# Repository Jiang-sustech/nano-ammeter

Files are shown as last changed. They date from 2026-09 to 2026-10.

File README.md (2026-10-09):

# 纳安表 (Nano-Ammeter)

基于电荷平衡原理的微弱电流测量仪，面向光电效应、脉冲电流等 pA 级测量场景。
硬件、固件、上位机与 PC 脚本全部开源。

## 1. 性能

| 项目 | 指标 | 条件 |
|---|---|---|
| 直流量程 | ±45 nA | 受参考电流 ±50 nA 限制 |
| 显示分辨率 | 0.01 pA | 固件量化 |
| 单次重复性 | 0.027 pA | 50 s 积分窗，1 pA–500 pA 段 31 点合并 |
| 线性度（校准后）| 0.0046 %FS | 162 点，满量程 ±45 nA |
| 脉冲峰值 | 4.2 µA | 超直流量程 93 倍，偏差 −0.58% |

装置输出量即积分窗口内的平均电流

$$I_{\text{out}}=\frac{1}{\tau}\int_{t-\tau}^{t} i(t)\,\mathrm{d}t$$

故对脉冲输入无需峰值检波、频谱搬移或同步采样，峰值远超直流量程时仍可正确读出等效平均值。

## 2. 仓库结构

| 目录 | 内容 |
|---|---|
| [`hardware/`](hardware/) | 嘉立创 EDA 源工程（含 BOM、网表）、原理图、4 层 Gerber |
| [`firmware-v1/`](firmware-v1/) | 固件，现役版本 |
| [`firmware-v0/`](firmware-v0/) | 固件，2026-09-13 冻结基线，只读 |
| [`pc-console/`](pc-console/) | 上位机：Web Serial 控制台 |
| [`scripts/smu/`](scripts/smu/) | 2636B 源表控制与采集 |
| [`scripts/plotting/`](scripts/plotting/) | 绘图 |
| [`scripts/analysis/`](scripts/analysis/) | 标定、拟合、线性度分析 |
| [`scripts/lib/`](scripts/lib/) | 公共模块，被上述脚本 import |
| [`scripts/misc/`](scripts/misc/) | 烧录与杂项 |
| [`docs/`](docs/) | 排障记录、实验方案、论文节 |
| [`data/`](data/) | 实测数据 |
| [`image_paper/`](image_paper/) | 论文插图 |
| [`prototypes/`](prototypes/) | 历史固件归档，只读 |

脚本索引与依赖关系见 [`scripts/README.md`](scripts/README.md)。

## 3. 硬件 `hardware/`

| 文件 | 说明 |
|---|---|
| `jlc-project.zip` | 嘉立创 EDA 专业版工程（原理图 + PCB + BOM + 网表）|
| `Schematic.png` | 原理图 |
| `gerber/` | Gerber 制板文件（4 层板 + 3 个钻孔文件）|
| `enclosure.stp` | 铝合金外壳 3D 模型（STEP）|

`jlc-project.zip` 解压得 `.epro2`，经嘉立创 EDA（专业版）`文件 → 打开工程` 导入；
元件属性含立创商城料号，可直接下单。

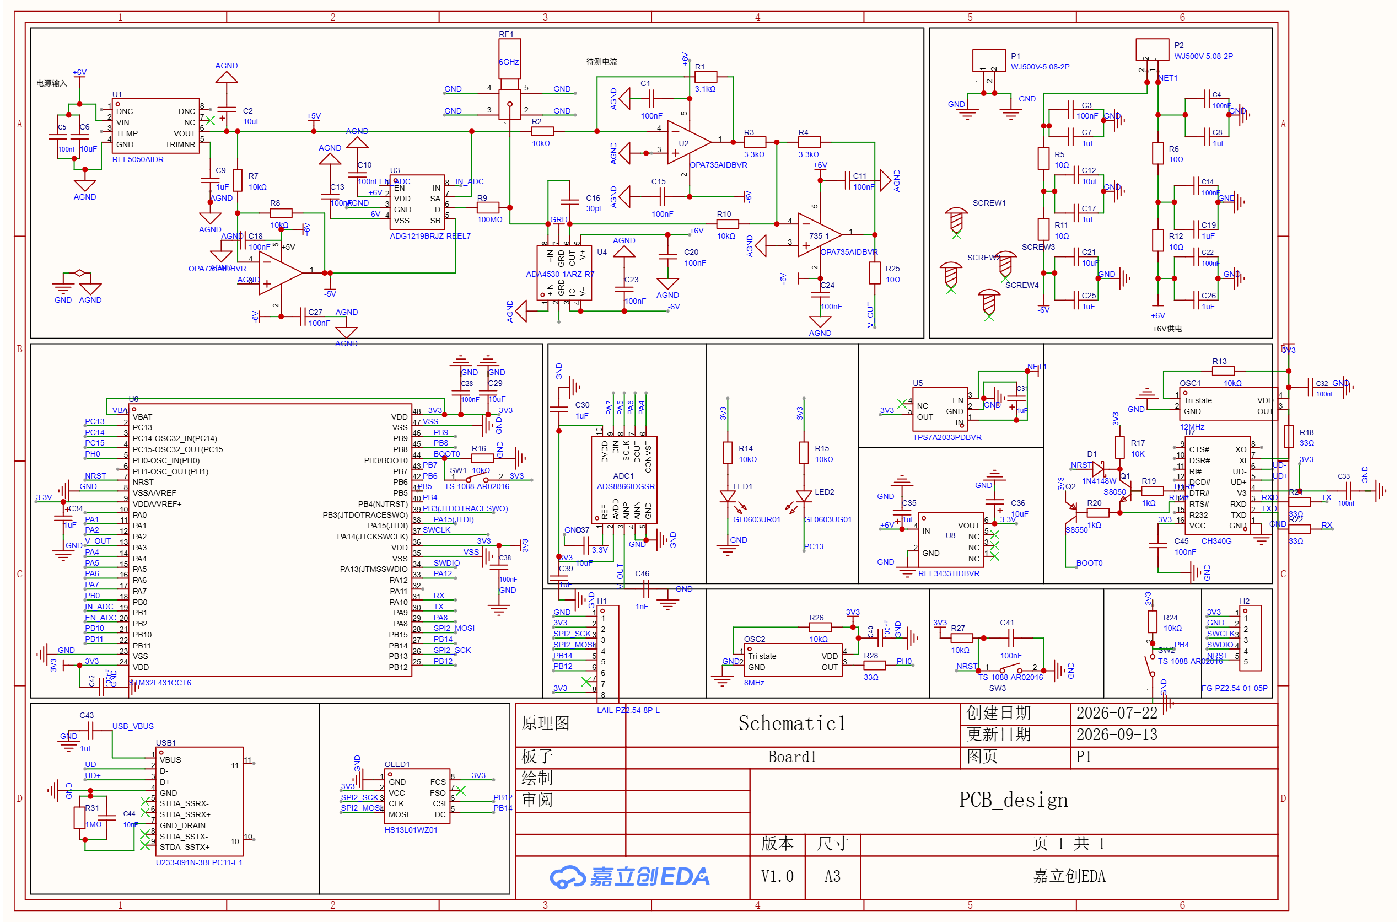
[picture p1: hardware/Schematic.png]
原理图


**板级配置**

| 项 | 器件 |
|---|---|
| MCU | STM32L431CCT6 |
| 模拟前端 | ADA4530 静电计运放（积分电容 100 pF）+ ADG1219 参考开关 + OPA735 电平移位 |
| 采集 | 内置 12-bit ADC（控制路）+ ADS8866 16-bit（观测路，SPI）|
| 显示 / 通信 | SH1106 1.3" OLED（SPI）/ 板载 CH340G（USB-C）|
| 参考电流 | ±50 nA（±5 V 经 100 MΩ，标称值）|

> 元件值均为标称值，绝对增益尚未标定；实测参考电流与积分电容值见
> [`firmware-v1/Core/Inc/current.h`](firmware-v1/Core/Inc/current.h)。

## 4. 固件 `firmware-v1/`

STM32L431 固件，CMake 工程（亦可由 CubeIDE 打开）。**固件改动仅限本目录**；
`firmware-v0/` 为冻结基线（只读），缺 50 s 长窗、拉回相、`X=` 字段与 `T<ms>` 指令，
不支持亚纳安测量。

`Core/Src/` 模块划分：

| 模块 | 职责 |
|---|---|
| `main.c` | 主循环、串口指令分发 |
| `measurement_state.c` | 测量状态机（空闲 / 拉回相 / 模式一 / 模式二）|
| `current.c` | ±50 nA 参考、式(6) 计算、分段校准 |
| `adc.c` `ads8866.c` | 双路同拍采集 |
| `cal_coef.c` `cal_mode.c` | 校准系数存储（Flash + CRC）、标定模式 |
| `sh1106.c` | OLED 显示 |
| `uart.c` | 串口协议、波形回传 |
| `tim.c` `spi.c` `gpio.c` `button.c` | 外设 |

```bash
cd firmware-v1
cmake --preset Debug && cmake --build build/Debug
# 产物：build/Debug/firmware-v1.elf
```

烧录：ST-Link + OpenOCD（`scripts/misc/run_app.sh` 可绕过"复位进 ROM bootloader"），
或串口 bootloader（`scripts/misc/uart_flash.py`）。

串口协议见 §9；固件内部细节见 [`firmware-v1/README.md`](firmware-v1/README.md)。

## 5. 2636B 源表控制与采集 `scripts/smu/`

Keithley 2636B（LAN / pyvisa），用于标定与表征；另含本装置的串口采集。

| 脚本 | 用途 |
|---|---|
| `cal_sweep.py` | 底层驱动（串口 + 源表 + 测量原语）|
| `sweep_dense.py` | 密集电流网格扫描（整窗回传）|
| `sweep_broad.py` `sweep_dc.py` `sweep_iv.py` | 宽范围 / 直流 / 光电探测器 I–V 扫描 |
| `sweep_pulse.py` | 脉冲采集（TSP 脉冲源）|
| `nanoammeter_capture.py` | 单次采集 → npz / png / log（v1 需 `--no-noise`）|
| `test_smu.py` | 源表连通与功能自检 |
| `warm_test.py` | 预热必要性对照 |
| `pulse_real.py` `pulse_probe.py` `pulse_introspect.py` | 脉冲重建 / 能力探针 / 内省 |
| `measure_transient.py` `switching_times.py` `range_test.py` | 瞬态 / 开关时序 / 量程效应 |
| `test_capture.py` | `nanoammeter_capture` 离线回归（26 项）|

```bash
pip install pyvisa pyserial numpy matplotlib
python scripts/smu/test_smu.py
python scripts/smu/nanoammeter_capture.py COM8 --no-noise
```

> `cal_sweep.py` 的 `MEASURE_TIMEOUT_S` 必须覆盖固件最长窗口（50 s → 已设 60）。

## 6. 绘图 `scripts/plotting/`

论文插图生成，统一风格见 `scripts/lib/paper_style.py`。

| 脚本 | 输出 |
|---|---|
| `paper_figs.py` | 低电流段图 |
| `paper_lin10_fig.py` | ±10 nA 组 |
| `paper_pulse_fig.py` | 脉冲四格图 |
| `photoelectric_fig.py` `photo_data_fig.py` `dark_current_fig.py` | 光电效应 / 光电数据 / 暗电流 |
| `residual_pct_plot.py` | ±5–45 nA 残差百分比图 |
| `console_figure.py` | 控制台截图（注入真实数据后 Chrome headless 渲染）|

## 7. 分析 `scripts/analysis/`

标定常数拟合、线性度、误差预算与脉冲分析。

| 脚本 | 用途 |
|---|---|
| `fit_constants.m` `make_fit_csv.py` | 三常数（M、I₊、I₋）最小二乘拟合 |
| `fit_linearity.py` `fit_tau.py` | 早期拟合链 |
| `cal_table.py` `detect_limit.py` | 标定表 / 检测下限 |
| `lowI_compare.py` | 误差链：装置 / 设定 / 源表回读 |
| `outlier_test.py` `.m` | 离群值检验（Python / MATLAB 互校）|
| `seg0_budget.py` `seg0_joint_fit.py` `fsw_hypothesis.py` | 低电流段偏置分析与假设检验 |
| `reproducibility.py` `endpoint_codes.py` `range_effect.py` `window_sawtooth.py` `raw_recalc.py` | 复现性 / 端点码 / 量程效应 / 锯齿形态 / 原始码反推 |
| `analyze_pulse.py` `sim_pulse_recover.py` | 脉冲分析 / 恢复仿真 |
| `matlab_utf8.sh` | MATLAB UTF-8 包装 |

推导见 [`docs/校准方案推导.md`](docs/校准方案推导.md)，操作步骤见
[`docs/拟合操作指南.md`](docs/拟合操作指南.md)。

## 8. 上位机 `pc-console/`

单文件 Web Serial 控制台，无外部依赖，Chrome / Edge 直接打开 `console.html`。

| 文件 | 说明 |
|---|---|
| `console.html` | 控制台；「一键采集」执行 `E→S→B→X→E`，「实验表征」面板负责逐点采集与系数收发（仅 v1）|
| `console_selftest.js` | 整体自测（36 项）|
| `console_src/archive.js` | 数据存档与命名模块，内联进 HTML |
| `console_src/archive_test.js` | 模块自测（18 项）|

```bash
node pc-console/console_src/archive_test.js
node pc-console/console_selftest.js
```

## 9. 测量与协议

**积分窗口**

| 电流 | 窗口 |
|---|---|
| $\lvert I \rvert \ge 1$ nA | 1 s |
| $\lvert I \rvert < 1$ nA | 50 s |

实测（1 pA–500 pA 段，31 点合并）：10 s 窗单次重复性 0.1153 pA，50 s 窗 0.0267 pA。
亚纳安段统一取 50 s，以保证光电效应实验 I–V 曲线过零点的判读精度。

**串口协议（115200 8N1）**

| 指令 | 功能 |
|---|---|
| `S` | 单次测量（测完回空闲）|
| `D` | 查询最近结果 |
| `B` / `X` | 回传窗口波形（内置 ADC / ADS8866），`"<tag> <count>\r\n"` + u16 小端 + 校验和 |
| `E` | 观测通路自检 |
| `Q` `Q<q_aC>,<i+_pA>,<i-_pA>` | 物理常数查询 / 写入（Flash，掉电不丢）|
| `K<段>,<a_ppm>,<b_fA>` `C` `Z` | 分段校准系数写入 / 查询 / 清除 |
| `T<ms>` | 强制积分窗口（`T0` 回自动）|

指令大小写不敏感，测量期间忽略。

## 10. 标定

式(6) 化简后仅需三个外部常数：

```
I = q·(c2 − c1)/T窗 − (m·I₊ + n·I₋)/N
  q = C·VREF/(65536·GAIN)   库仑/码   标称 1.5259e-14
  I₊, I₋                    参考电流  标称 ±50 nA
```

简化：① 电平移位 1.55 V 在 `Vo1 − Vo2` 中相消，无需标定；② `q` 的四个因子只测乘积。

| 量 | 方法 |
|---|---|
| `I₊` / `I₋` | 闭环最小二乘（`analysis/fit_constants.m`）|
| `q` | 灌已知电流开环测量，不依赖锯齿相位假设 |

> `q` 不可用"参考断开 + 灌电流"法：`EN=0` 为 Hi-Z 而非 0 A，浮空节点寄生电容会注入
> 衰减暂态电荷。见 [`docs/调试与排障.md`](docs/调试与排障.md)。

`firmware-v0` 常数存编译期宏；`firmware-v1` 存 Flash 末页（带 CRC），串口 `Q`/`K` 读写，
重新标定无需重编译。

## 11. 排障

调试手段、工程结论与待复核项见 [`docs/调试与排障.md`](docs/调试与排障.md)。

> 该记录对应一版存在设计缺陷的硬件，其中的硬件接线与结论不具通用性；作者将在开源方案
> 中发布修正后的硬件版本，届时以新版文档为准。

## 许可

尚未选定。
（硬件建议 CERN-OHL-P 或 CC BY-SA；固件与脚本建议 MIT 或 Apache-2.0。）

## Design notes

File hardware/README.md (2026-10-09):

# 硬件文件

纳安表的原理图与制板文件。

## 内容

| 文件 | 说明 |
|---|---|
| [`jlc-project.zip`](jlc-project.zip) | **嘉立创EDA专业版工程源文件**（原理图 + PCB + BOM + 网表）|
| [`Schematic.png`](Schematic.png) | 原理图（整页）|
| [`gerber/`](gerber/) | Gerber 制板文件（4 层板 + 3 个钻孔文件）|
| [`enclosure.stp`](enclosure.stp) | **铝合金外壳 3D 模型**（嘉立创 FA 壳体，STEP 格式）|

## 外壳（嘉立创 FA 铝合金壳体）

`enclosure.stp` 是整机的铝合金外壳模型（STEP AP214），导入 SolidWorks / Fusion 360 /
FreeCAD 等即可查看或二次修改。模型来自嘉立创 FA 的壳体定制服务。

> STEP 文件头里的作者字段（`Gilles Foucault` / `UJF`）是嘉立创导出模板的**默认占位**，
> 非设计者信息。

## 源工程（嘉立创EDA专业版）

`jlc-project.zip` 解压后是 `.epro2` 工程包，用**嘉立创EDA（专业版）**
`文件 → 打开工程` 直接导入。工程内已包含原理图、PCB 版图、BOM 与网表，
元件属性带立创商城（LCSC）编号，可直接下单。

> 源工程不含姓名、邮箱、本地路径等个人信息（仅含 LCSC 厂商/料号等公开数据）。

## 板子概况

- **4 层板**（`G1` / `G2` 为内层）
- MCU：STM32L431CCT6
- 模拟前端：ADA4530 静电计运放（积分电容 100 pF）+ ADG1219 参考开关 + OPA735 电平移位
- 采集：内置 12-bit ADC（控制路）+ ADS8866 16-bit（观测路，SPI）
- 显示：SH1106 1.3" OLED（SPI）
- 串口：板载 CH340G（USB-C）
- 参考电流：±50 nA（由 ±5 V 经 100 MΩ 得到，**标称值**）

## Gerber 层对应

| 文件 | 层 |
|---|---|
| `Gerber_TopLayer.GTL` | 顶层铜 |
| `Gerber_InnerLayer1.G1` | 内层 1 |
| `Gerber_InnerLayer2.G2` | 内层 2 |
| `Gerber_BottomLayer.GBL` | 底层铜 |
| `Gerber_TopSilkscreenLayer.GTO` | 顶层丝印 |
| `Gerber_BottomSilkscreenLayer.GBO` | 底层丝印 |
| `Gerber_TopSolderMaskLayer.GTS` | 顶层阻焊 |
| `Gerber_BottomSolderMaskLayer.GBS` | 底层阻焊 |
| `Gerber_TopPasteMaskLayer.GTP` | 顶层钢网 |
| `Gerber_BoardOutlineLayer.GKO` | 板框 |
| `Gerber_DocumentLayer.GDL` | 文档层 |
| `Gerber_DrillDrawingLayer.GDD` | 钻孔图 |
| `Drill_PTH_Through.DRL` | 通孔（镀铜）|
| `Drill_PTH_Through_Via.DRL` | 过孔 |
| `Drill_NPTH_Through.DRL` | 非镀铜孔 |

`FlyingProbeTesting.json` 与 `PCB下单必读.txt` 是 EasyEDA 导出时附带的标准文件，
非设计内容。

> 导出工具：**EasyEDA Pro**。Gerber 注释里不含姓名、路径或邮箱等个人信息。

## 注意

- **元件值与阈值均为标称值**，绝对增益尚未标定。实际测得的参考电流与
  积分电容值见 `firmware-v1/Core/Inc/current.h` 的注释
  （`I_POS` / `I_NEG` 处记录了实测方法与结果）。
- 制板前请自行复核板框、钻孔与阻抗要求；本仓库不对制板结果负责。
- 未经许可证选定，**请勿视为已授权使用**（见仓库根 README 的「许可」一节）。

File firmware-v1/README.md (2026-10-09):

# firmware-v1 — 现役固件

> ## 本工程与 `firmware-v0/` 的关系（2026-09-20 更正）

```
firmware-v1/   现役固件（本工程）—— 被烧录的就是它, 全部论文数据出自它
firmware-v0/   冻结的旧基线 —— 停在 2026-09-13 那次同步时的样子
```

**两者不是"两代产品"，是同一份代码的两个时点。** 2026-09-13 做过一次整份同步，
之后开发**全部只进本工程**，v0 再没动过。今天相差 **1124 行 / 8 个文件**：

| 文件 | 差异 |
|---|---|
| `Core/Src/current.c` | 594 行 —— 拉回相、50 s 长窗口、小电流模式 |
| `Core/Src/main.c` | 148 行 —— `X=`/`T=` 结果行、窗口切换显示 |
| `Core/Src/measurement_state.c` | 138 行 —— 自动窗口选择 |
| `Core/Inc/current.h` | 123 行 —— `CURRENT_WIN_LONG_TICKS` 等 |
| `Core/Inc/measurement_state.h` | 37 行 |
| `Core/Src/uart.c` | 37 行 |
| `Core/Src/cal_mode.c` | 34 行 |
| `Core/Inc/uart.h` | 13 行 |

⚠️ **v0 里 `CURRENT_WIN_LONG_TICKS` 一处都没有 → 它做不了亚纳安测量。**
论文里 1 pA ~ 1 nA 那一段的数据，用 v0 复现不出来。

### ⚠️ 本文档原先记的"防漂移约定"已作废

改名前这里写着「**唯一**的差别是 `M` 手动连采指令」「判断标准：差异必须只有那
四处」「多出来的就是漏同步」，还配了一套三步流程（改 v1 → 验证 → 同步回 v0）。

**那套约定从 2026-09-13 之后从没执行过。** 话在当时是对的，但第三步没人做，
于是实际差异长成了它自己声称的 **280 倍**。现在把事实记在这里，不再假装两边
应当一致：

- `firmware-v1/` 是**唯一在开发**的固件
- `firmware-v0/` **只读**，不再往回同步任何改动
- 需要 v0 的某个特性时**去 git 历史里翻**，不要指望它跟得上

> `M` 手动连采指令（`Current_ManualRun` / `Current_ManualLine`）仍然只在 v1 里，
> 但它今天早已不是两者唯一的差别。

### 双斜率硬积分已从**两个**工程删除（2026-09-13）

原"模式二 双斜率硬积分"（<1 nA，下限约 6 pA）废弃，由**小电流模式**取代：
双斜率在 1 pA 时上积相要 `t1 = C·ΔV/I = 100pF×2V/1pA = 200 秒`，而预算只有
10 秒 —— 连一个循环都跑不完。小电流根本不需要参考电流拉回：1 pA 积 3 秒才
30 mV，离 ±4.3 V 的轨远得很，直接积、测首尾两点即可。

**还有一个当时没意识到的理由**：双斜率靠 `EN=0`（Hi-Z）做"零参考"，而那个
浮空节点的寄生电容会注入一个指数衰减的暂态电荷（实测 `C_p ≈ 4.9 pF`、
`τ ≈ 490 µs`、`Q ≈ 24 pC`）。小电流模式同样受它影响，但**可控** ——
把 `SI_SETTLE_TICKS` 加大到 `>5τ` 即可（已改为 128 次 ≈ 3.0 ms）。

> `SI_SETTLE_TICKS` 的单位是**阻塞 `ReadBoth` 的次数**（每次约 23.6 µs），
> **不是 160 µs 的 TIM6 拍**。旧注释写成"稳定拍数"会让读者差 6.8 倍。

## v0 与 v1 仍然逐字节相同的部分

这些是**硬件驱动层与物理常数存储**，到今天两边同源（`Drivers/` 整个目录也
完全一致）。改一边时想想另一边是否还在用：

```
Core/Src/adc.c                                <- 一致
Core/Src/ads8866.c   Core/Inc/ads8866.h       <- 一致; 含坏读判据的驱动层
Core/Src/sh1106.c                             <- 一致
Core/Src/cal_coef.c  Core/Inc/cal_coef.h      <- 一致; 物理常数存储
STM32L431xx_FLASH.ld                          <- 仅注释不同, 存储区定义相同
Drivers/                                      <- 整个目录逐字节一致
```

```bash
cd nanoammeter_repo
for f in Core/Src/cal_coef.c Core/Inc/cal_coef.h \
         Core/Src/adc.c Core/Src/ads8866.c Core/Inc/ads8866.h Core/Src/sh1106.c; do
  diff -q firmware-v1/$f firmware-v0/$f && echo "一致 $f"
done
diff -rq firmware-v1/Drivers firmware-v0/Drivers
# STM32L431xx_FLASH.ld 不在上面 —— 它只有注释不同, 用 diff 看一眼即可
```

> **链接脚本那一页两边都留住了。** `firmware-v0` 原来没留（它那时也没有
> `cal_coef.c`），同步进 `cal_coef` 之后补上了 —— 否则代码长到 `0x0803F800`
> 那一页上，`Cal_Save()` 一写就把自己的代码擦了。

## 构建

```bash
cmake --preset Debug
cmake --build build/Debug          # 产出 firmware-v1.elf
```

## 与上位机的关系

两个固件**共用同一个控制台** `../console.html`。
控制台里的「实验表征」面板只在与本固件通信时有用；
对着 `firmware-v0` 用时该面板不会响应（系数查询无回包）。

## 扩展协议（仅本固件有）

在 `firmware-v0` 原有协议（`S`/`D`/`B`/`X`/`E`）之上增加以下指令。

### 为什么要用整数传系数

MCU 端**不做浮点文本解析**（`strtof` 体积大、行为受 locale 影响）。
系数一律用**定标整数**传：

| 量 | 定标 | 例 |
|---|---|---|
| 增益 `a` | × 1e6（ppm） | `a = 0.998765` → `998765` |
| 偏置 `b` | × 1e15（fA） | `b = -0.123 pA` → `-123` |

上位机负责换算，MCU 收到后转成 float 存。

### 量程分段（三个，按电流绝对值）

| 段号 | 量程 | 判定 |
|---|---|---|
| `0` | **1 pA – 1 nA**（小电流） | `\|I\| < 1 nA` |
| `1` | **1 nA – 10 nA** | `1 nA ≤ \|I\| < 10 nA` |
| `2` | **10 nA – 45 nA** | `10 nA ≤ \|I\| ≤ 45 nA` |

分段**按绝对值**，正负共用一段（增益误差与符号无关，正负各拟合一套会
让每段点数减半、统计可靠性下降）。报告如需按符号分表，导出 CSV 里带符号，
在 MATLAB 里筛即可。

### 用哪一路 ADC 出结果（重要）

**ADS8866（外部 16 位）是最终结果的标准**，内置 ADC 只作对照。
原因：内置是 12 位左移 4 位（有效分辨率 16 码），在 1 pA 量程下量化误差
达 25%；ADS8866 是 1 码，同样条件下 1.5%。

结果行**两路都报**，便于逐点对照（也便于报告里写"内置/外部一致性"）：

```
I=+25.274 nA X=+25.271 nA MODE=1 T=1000ms CAL=+25.270 RAW m=5003 n=6251 INT1=58962 INT2=2601 EXT1=58900 EXT2=2540
```

| 字段 | 含义 |
|---|---|
| `I=` | 由**内置 ADC** 算出的原始值（保持与原固件兼容） |
| `X=` | 由 **ADS8866** 算出的原始值 ← **拟合用的就是这个** |
| `T=` | 实际积分时长（ms）。模式一恒为 1000ms；小电流模式是设定值，撞轨提前收尾时更短 —— 报告里 `I = C·ΔV/T` 的 T 就是它，**必须记录** |
| `CAL=` | `X=` 经分段校准模型后的最终输出（未校准时不出这个字段） |
| ` TIMEOUT` | 后缀。本固件已无模式二，正常不会出现；保留解析是为了兼容 `firmware-v0` |
| `RAW …` | **模式一专属**的原始量，见下 |

> 上位机的 `I=` 解析正则不锚定行尾，追加字段不会破坏现有解析。

### `RAW` 段：模式一的原始量

| 字段 | 含义 |
|---|---|
| `m=` / `n=` | 窗口内 **POS / NEG 注入的周期数**。式(6) 的分母就是 `m+n` |
| `INT1=` / `INT2=` | 内置 ADC 那路的**窗口两端**原始码 |
| `EXT1=` / `EXT2=` | ADS8866 那路的窗口两端原始码 ← 拟合用这组 |

> `INT1`/`EXT1` 是**拉回相最后一拍**的采样（记作 `V_01`），不是 `voltage_buf[0]` ——
> 式(6) 用的端点就是它。见下文「窗口两端的对齐」。

**为什么要在结果行里带这些**：只报电流值的话，`m`/`n` 和两端码就丢了，
而这两件事都必须从**同一次测量**的原始量出发：

1. **离线复核** —— 拿实测的 `m`/`n`/两端码可以把式(6) 整个重算一遍，
   不用反推（报告表 4-9~4-14 要的也是这些量）
2. **分段系数 `a`/`b` 的拟合**

### 窗口两端的对齐（为什么分母就是 `m+n`）

**拉回相搬进了 TIM6 中断**，所以节拍是这样对齐的：

```
节拍 0..p        拉回相（把积分器拉到接近 0V，不计数、不进缓冲）
节拍 p           V_01 → 窗口起点          ← 就是这一拍
节拍 p+1..p+6250 窗口采样 → voltage_buf[0..6249]，每拍计一次数
```

窗口两端（`V_01` 与最后一个窗口采样）**都是 ISR 采样**，采样偏移完全相同；
而计数覆盖的正好是它们之间的 **6250 个间隔**。于是：

```
n_total = m_count + n_count = 6250      ← 不用减一
窗口时长 = 6250 × 160µs = 1.000 s 整     ← 不用再凑
```

**论文的 `(m+n)` 形式因此精确成立。**

> 为什么必须搬进中断：若在主循环里拉回，`V_01` 到采样点 0 的间隔是
> `160µs + 读一次 ADC 的耗时 + 启动 TIM6 的代码延时`，比整一拍多出后面两项。
> 那一截是实打实的参考注入但不属于任何一拍，折算约 0.5~1 pA 的恒定误差，
> 而且依赖编译结果、说不清来源。

小电流模式（`MODE=2`）**不出** `RAW` 段：它不算 `m`/`n`，用的是起点/终点两段
平均，原始量是另一套（`T=` 已经给了它的实际积分拍数）。

`scripts/smu/nanoammeter_capture.py` 会把这一段解析进 npz 的 `raw_m` / `raw_n` /
`raw_int1` … 字段；没有这一段时一律记 `-1`（**不伪造成 0**）。

### 校准系数指令

| 指令 | 作用 | 响应 |
|---|---|---|
| `C` | 查询分段系数 | 未标定：`CAL NONE`<br>已标定：`CAL 3 <a0>,<b0> <a1>,<b1> <a2>,<b2>` |
| `K<seg>,<a_ppm>,<b_fA>` | 写入某段系数 | 成功：`CAL SET <seg> <a_ppm>,<b_fA>`<br>失败：`CAL ERR <原因>` |
| `Z` | 清除**分段系数**（恢复 a=1, b=0） | `CAL CLEAR` |

响应示例：`CAL 3 998765,-123 1000234,56 999123,-12`

> **`C` 的响应格式不能追加字段** —— 上位机正则锚定行尾
> （`/^CAL 3 (\S+) (\S+) (\S+)$/`）。物理常数因此走下面单独一组指令。

### 物理常数指令（`q` / `I₊` / `I₋`）

计算电流要用的物理量：

```
I = q·(c2 − c1)/T窗 − (m·I₊ + n·I₋)/N          T窗 = N·160µs

  q = C·VREF/(65536·GAIN)   库仑/码
```

**`q` 的 4 个因子不必分开测** —— 只测乘积。而且 `C` 和电平移位增益**分不开、
也不用分**：`C` 在整个公式里只出现在 `q` 里。

| 指令 | 作用 | 响应 |
|---|---|---|
| `Q` | 查询物理常数 | `CAL Q <q_aC>,<i+_pA>,<i-_pA>` |
| `Q<q_aC>,<i+_pA>,<i-_pA>` | 写入 | 成功：`CAL Q SET <...>`<br>失败：`CAL ERR <原因>` |

定标：`q` 为 **aC/码**（×1e18，标称 `15259`），`I₊`/`I₋` 为 **pA**（×1e12，
实测 `50232` / `-50255`）。

**写入时会校验符号**（必须 `I₊ > 0 > I₋`）和量级。符号写反会让整个公式静默
反向 —— 这是本架构最容易出错也最难发现的地方，所以直接拒收而不是记下来。

**`Z` 不会清掉 `q`/`I₊`/`I₋`。** 它们是仪器的**实测属性**，不是拟合出来的修正；
清掉等于把仪器退回全标称状态。

### `q` 怎么测（没有精密源也能做）

```
参考断开（ADG 关），灌一个已知电流 I，积 T 秒，读首尾码差 Δc：

    q = I·T / Δc
```

两点一除，**没有拟合**。要求积分期间不撞轨（撞轨后码饱和，Δc 是假的）。
已知电流可来自源表（如 2636B，±0.1%）—— 接到**仪器输入端**，不碰参考通路。

系数存在 Flash 最后一页（`0x0803F800`），掉电不丢。

## 待办（2026-09-12 记）

### 1. ~~原始量诊断输出~~ ✅ 已完成

已加到结果行的 `RAW` 段（见上文「RAW 段」），`m`/`n`/首尾两路原始码都出。
采集脚本会解析进 npz，控制台侧不改也能用（解析是前缀匹配）。

### 2. 端点直线拟合（提高分辨力）

**实测分辨力现状**（用 09-11 实采数据 + 二阶差分/MAD 估噪声）：

| | 单点噪声 | 单次分辨力 |
|---|---|---|
| 内置 ADC | 48.4 码 | — |
| ADS8866 | 49.0 码 | — |

**两种 ADC 的噪声一样** —— 说明噪声来自模拟前端（积分器 + 电平移位），
不在 ADC 里。**所以换 ADS8866 对分辨力没有帮助**（与早先的猜测相反）。

| 模式 | 单次分辨力 |
|---|---|
| 模式一（1 秒窗口） | **~1.0 pA** |
| 小电流模式（3 秒纯积分，端点 8 点平均） | **~0.13 pA** |

模式一慢在端点用**单点采样**（`voltage_buf[0]` / `voltage_buf[N−1]`）。
端点落在斜坡上（每拍约 480 码），不能直接平均（会挪到质心），
但可以**取末尾 K 点做直线拟合、外推到端点那一拍**：

| K | 噪声 | 分辨力 |
|---|---|---|
| 1（现在） | 68 码 | 1.04 pA |
| 8 | 24 码 | 0.37 pA |
| 16 | 17 码 | 0.26 pA |

### 3. ~~分母取 (m+n) 还是 (m+n−1)~~ ✅ 已解决

把拉回相搬进 TIM6 中断之后，窗口两端都是 ISR 采样、计数与间隔一一对应，
**分母就是 `m+n`，不用减一**。详见上文「窗口两端的对齐」。

旧的两种写法差在：

| | 差距 | 来源 |
|---|---|---|
| 分母 | `(N−1)/N = 0.99984` | 窗口只有 N−1 个间隔 |
| 计数 | `I₊/N = 8.04 pA` | 多出来那一拍的归属 |

**两个都是纯算术，可以在纸上核。** 现在两个都消失了。

### 4. 已确认的物理事实（供报告用）

**参考电流的共模偏移以 1:1 进入读数**：

```
comp = [(m−n)·I + (m+n)·d] / N      d = (I₊ + I₋)/2
                                └─ 系数 ≈ 1, 无衰减
```

实测 `d = (50.232 − 50.255)/2 = −11.5 pA` → 每个读数偏 +11.5 pA。
**这台仪器的绝对准确度主要由两个参考电流的共模稳定性决定**，
I₊/I₋ 的温漂会 1:1 传进读数（报告 4.7 节不确定度预算里权重最大的一项）。

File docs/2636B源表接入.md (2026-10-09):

# 2636B 源表接入

> 本文是 `tools/keithley/`（2026-09 早期的一套独立工具链）删除前**抢救出来的知识**。
> 那套代码本身已被 `scripts/smu/cal_sweep.py` 取代（同样走 pyvisa，且不需要 NI-VISA），
> 但下面几条是踩坑踩出来的，`docs/` 里原本没有，删掉就没了。

---

## 一、2636B 用 TSP，不是 SCPI

**这是本项目最容易踩的坑。**

2600B 系列（含 2636B）的原生远程语言是 **TSP**（Test Script Processor，内嵌 Lua）。
常规 SCPI 命令（`:SOUR:CURR`、`:SENS:FUNC:ON` 等）在 2636B 上**默认不可用**。

要用 SCPI 只有两条路，且都只为迁移 2400 的旧代码而存在：

| 路线 | 做法 | 代价 |
|---|---|---|
| 2400 仿真 | 加载 `Persona2400` / `2600B-800A.tsp` | 整机变成 2400，行为不再等价于 2636B |
| 逐条桥接 | `Initialize2400()` 后用 `Execute2400("<SCPI>")` | 每条命令包一层，且部分命令不完全兼容 |

**本项目一律用原生 TSP。** 现有脚本里的写法一律是
`smu.write('smua.source.leveli = ...')` 这种 Lua 语句，不是 SCPI。

### ⚠️ 没有 `measure.func` —— 别照抄 2400/SCPI 的写法（2026-09-21 实测）

写 `scripts/smu/sweep_iv.py` 时按习惯写了：

```python
smu.write('smua.measure.func = smua.MEASURE_DCVOLTS')      # ✗ 错的
```

仪器报回：

```
-286  TSP Runtime error at line 1: Cannot modify read only table.
```

因为 **`smua.measure` 是一张只读表**：`rangev` / `autorangev` / `rangei` /
`autorangei` / `nplc` / `autozero` 是它**已有的键**（可以赋值），而 `func`
不是 —— 给只读表加新键就报这个错。同时 `smua.MEASURE_DCVOLTS`、
`smua.MEASURE_DCAMPS` 这些常量**也都是 `nil`**。

| 探测 | 结果 |
|---|---|
| `smua.measure.func` | `nil` ✗ |
| `smua.MEASURE_DCVOLTS` | `nil` ✗ |
| `smua.measure.rangev` / `autorangev` / `nplc` / `autozero` | 真值 ✓ |
| `smua.measure.v` / `smub.measure.i` | `function` ✓ |

**2600B 上测量功能不靠属性切换** —— 直接调 `measure.v()` / `measure.i()`，
电压量程走 `measure.autorangev`、电流量程走 `measure.autorangei`，互不干扰。

> 为什么现有脚本没踩到：`cal_sweep.py` 一直是源电流 + 测电流，只用到
> `measure.autorangei` 这类**真实存在**的键，从没碰过 `func`。
> 这个坑只在"想显式指定测量功能"时才会露头。
>
> **另一条通用教训**：写完配置一定要读 `errorqueue`（`cal_sweep.smu_write()`
> 已经内置了这件事）。上面这条错误**不会让 write 失败**，静默留在队列里，
> 不查就永远不知道配置根本没生效。

### ⚠️ `measure.delay` 出厂是自动值，会让电流测量慢 42 倍（2026-09-21 实测）

写 `scripts/smu/sweep_iv.py` 时发现扫描每点要 1.4 s，查了半天。结论：

**`measure.delay = -1`（出厂/自动）对电流测量会算出一个 ~900 ms 的延时。**

| NPLC | `measure.i()` | `measure.v()` |
|---|---|---|
| 0.01 | 902.6 ms | 2.1 ms |
| 0.1 | 911.6 ms | 4.1 ms |
| 1 | 922.8 ms | 22.6 ms |
| 10 | 1102.9 ms | 202.9 ms |

`measure.v()` 干净地随 NPLC 走（NPLC × 20 ms，线频 50 Hz）；
`measure.i()` 是 **~900 ms 固定值 + NPLC 项**，那 900 ms 与 NPLC、电流档位、
自动量程、输出开关**全都无关**。

设 `measure.delay = 0` → **923 ms 降到 4.3 ms**。

**它不是"稳了才快"的取舍，是纯亏** —— 同一电压连读 20 次：

| `measure.delay` | 标准差 | 极差 | 每次 |
|---|---|---|---|
| `0` | **1.96e-15 A** | 8.2e-15 A | 22 ms |
| `-1` | 4.04e-15 A | 1.28e-14 A | 923 ms |

不开延时反而**散布更小**。所以现行脚本一律显式写 `measure.delay = 0`，
靠自己的 `--settle` 控制换点稳定。

> 排查时走过的弯路，记下来免得重走：
> ① 先怀疑 socket 往返 —— **错**，实测每次 query 约 2 ms；
> ② 再怀疑 `autozero` —— **错**，autozero 0/1/2 都是 22 ms；
> ③ 再怀疑自动量程换档 —— **错**，锁死档位还是 923 ms；
> ④ 最后按 NPLC 缩放才看出有个**不随 NPLC 变的固定项**，顺着找到 `delay`。
> 判据是"**固定项 vs 缩放项**"，不是逐个猜。

### ⚠️ 串联测电流要用 **0 V 电压源**，不是 0 A 电流源（2026-09-21 实测）

写 `scripts/smu/sweep_iv.py` 时想把 B 路当电流表，第一版写了：

```python
smu.write('smub.source.func   = smub.OUTPUT_DCAMPS')
smu.write('smub.source.leveli = 0')          # ✗ 以为是"零压降电流表"
```

**这是错的。** 0 A 电流源在串联回路里会调整自己的电压去**阻止**电流流过 ——
它是个"堵路"的，不是电流表。

现场症状很能说明问题：B 的端电压**稳定等于 A 施加电压的 0.6 倍**（纯分压），
而 A 明明灌了 25 pA，B 只读到 0.5 pA。

```python
# ✓ 正解: 0 V 电压源 = 理想短路, 零压降, 电流自由通过
smu.write('smub.source.func   = smub.OUTPUT_DCVOLTS')
smu.write('smub.source.levelv = 0')
smu.write('smub.source.limiti = 1e-3')        # 对电压源, 合规量是电流
```

改完 B 端电压立刻从"分压跟随"掉到 **10 µV** —— 那才是零负担电流表。

**一般规则：串联测电流用电压源 0 V，不要用电流源 0 A。**

> 推论：**单通道模式（`--single`）反而最不容易搞错** —— 让源电压的那个通道
> 自己 `measure.i()`，源和测共用一套输出级，天然串联，不存在"谁的 LO 接哪"
> 的问题。双通道要多接两条线，每一处都可能是断的。

### 接线的自检判据：`|I_A| ≈ |I_B|` 且符号相反

双通道接好后**不要直接扫**，先做这个检查：A 源电压、B 当电流表，读两路电流。

| 现象 | 含义 |
|---|---|
| `I_A/I_B ≈ −1`，B 端电压 ≈ 0 | ✓ 电流确实穿过 B，可以测了 |
| 比值远大于 1（如 +12、−100） | ✗ B 不在回路里，任何 I-V 数据都不可信 |
| B 端电压顶在合规值 | ✗ B 的 LO 没有返回路径 |

道理很直白：**A 灌进去多少，B 就必须读出来多少** —— 同一个电流串在一条路上。
比值不是 −1，就是有别的路径把电流分走了，或者 B 根本没接上。

---

## 二、连接方式

现行脚本用 `pyvisa.ResourceManager('@py')` —— **纯 Python 后端（pyvisa-py），
不需要 NI-VISA**。LAN（`TCPIP0::<ip>::5025::SOCKET`）和 USB 都可以走这条路。

> 历史：早期设想过走 NI-VISA，被"没装 NI-VISA"卡住。NI-VISA 约 1.5 GB、
> 需要管理员权限、下载页是 JS 单页应用（没有直链，`winget` 也搜不到）。
> **后来发现 pyvisa-py 就够了，那条路没必要走。**

⚠️ **一个已避开的陷阱**：不写 `'@py'` 时，`pyvisa.ResourceManager()` 在
NI-VISA 缺失时会**静默回退**到 pyvisa-py，让你误以为一切正常。现行脚本显式
指定 `'@py'`，所以不会踩到。

---

## 三、安全关断状态（**这条原本缺失，2026-09-15 已补进 `cal_sweep.py:smu_open()`**）

2636B 出厂时：

```
offmode  = OUTPUT_NORMAL      -> "关输出"后线上仍是一台 0 A 电流源
offlimitv = 40 V              -> 而那台 0 A 电流源的限压是 40 V
```

**也就是关输出之后，被测节点上挂的是 40 V。** 对 ADA4530-1 这类高阻输入级
是危险的。而本工程每个测量点之间、每次换档都会关一次输出，所以这不是理论风险。

现行设置：

| 项 | 出厂 | 本工程 | 理由 |
|---|---|---|---|
| `offmode` | `OUTPUT_NORMAL` | `OUTPUT_NORMAL` | **不用 `OUTPUT_HIGH_Z`**：手册明确警告它会磨损输出继电器，扫描时频繁开关不可取 |
| `offfunc` | 电压源 | `OUTPUT_DCAMPS` | 关输出时是"0 A 电流源" |
| `offlimitv` | **40 V** | **2 V** | 压到被测电路能承受的水平 |

**两个必须记住的坑：**

1. **`smua.reset()`（或 `*RST`）会把 `offlimitv` 打回 40 V。**
   所以 `reset()` 之后**必须紧接着**重设安全关断状态，否则前面设的等于没设。
2. **顺序**：先关输出 → 再改限压 → 最后才开输出。
   `cal_sweep.py` 里由 `smu_set()` 保证，不要绕开它自己拼命令。

---

## 四、顺从电压（`source.limitv`）：判据是"钳位二极管永不通"，不是"够不够用"

现行值 **5 V**（原来设 20 V）。依据见下。

两条手册事实凑在一起，推出一个**不是理论风险**的失效路径：

| 器件 | 手册原文 | 数字 |
|---|---|---|
| **ADA4530-1** | 输入绝对最大值 `(V−)−0.3 V ~ (V+)+0.3 V`。超过后钳位二极管导通，此时**必须把电流限到 ≤10 mA**，否则永久损坏 | **10 mA** |
| **Keithley 2600B** | 顺从限不被超过的**唯一例外**是 ISOURCE 下的 VLIMIT：「the VLIMIT will source or sink **up to 102 mA** for ISOURCE ranges on or below 100 mA」 | **102 mA** |

**关键在那个"唯一例外"**：电流源模式下，一旦输出顶到电压合规，仪器**就不再受
`leveli` 约束**，可以灌出 102 mA —— 比 ADA4530-1 的损坏阈值高 **10 倍**。

```
limitv = 20 V, 运放轨 ±5 V
  -> 输入开路/异常 -> 源表把节点顶到 20 V
  -> ADA4530-1 钳位二极管在 5.3 V 导通
  -> 二极管一导通, 2600B 的 ISOURCE VLIMIT 例外生效 -> 最多 102 mA
  -> 10 mA 就能烧掉它

limitv ≤ (轨电压 + 0.3 V)
  -> 节点永远到不了导通阈值 -> 那条 102 mA 的路根本不开
```

### 两条阈值（运放轨 ±6 V 时）

> 轨电压由用户报为 **±6 V**，**待实测确认**（2026-09-15）。

```
轨 = ±6 V
  ├─ 损坏边界: 绝对最大值 = 轨 ± 0.3 V      -> 节点必须 < 6.3 V
  │              超过则钳位二极管导通 -> 打开那条 102 mA 的路
  └─ 规格内边界: IVR = V− ~ V+ − 1.5 V      -> 节点应 < +4.5 V
                 超出 IVR 不损坏(有 keep-alive 级), 但运放不在规格内
```

**现行 `limitv = 5 V` 卡在这两条之间**：离损坏边界 6.3 V 还有 26% 余量，
但若输入开路、节点被顶到 5 V，会超出 IVR（不损坏，但不可信）。

选值的判据因此是：

```
理想:  limitv <= 4.5 V      (既远离损坏边界, 又保证故障时也在 IVR 内)
下限:  必须 > 正常工作所需电压, 否则静默截顶
```

### 线性假设已被证伪（不用实测）

那 0.5 V 有两种解释，其中**线性那一种可以直接排除**：

```
若 "2 nA -> 0.5 V" 是线性的 (输入阻抗 250 MΩ)
  -> 45 nA 需要 11 V
  -> 11 V 远超绝对最大值 6.3 V -> 钳位二极管导通 -> 102 mA 通路打开
  -> 输入级早该烧了

而 36 点标定在 ±40 nA 上反复跑过, 输入级完好。
=> 线性假设不成立。45 nA 所需电压必然 < 6.3 V, 且几乎肯定远小于它。
=> 那 0.5 V 是**固定偏置**或测量假象, 不是负载压降。
```

**推论**：所需电压上限被"输入级没烧"这件事本身钉死在 6.3 V 以下 —— 这是**硬的上界**，
因为它来自一次已经发生且成功的实验。

> ⚠️ **仍待实测两点**
> 1. **运放电源轨到底多少伏** —— 用户说要实测。若实际是 ±12 V / ±15 V，
>    上面两条阈值跟着变，5 V 会偏保守。
> 2. **所需电压到底多少**（只为定余量，不影响"够不够用"的结论）。
>
> **验证**（一条命令）：
>
> ```python
> smu.write('smua.source.output = smu.OUTPUT_ON')
> smu.write('smua.source.leveli = 45e-9')
> print(smu.query('print(smua.measure.v())'))
> ```
>
> 接近 5 V → 要调回 20 V 并查输入级；零点几伏 → 5 V 足够。

### 另一条相关的：低电流档的建立时间

2600B 手册另有一张 **"maximum DUT impedance for specified settling time"** 表，
警告在 1 nA 这类低电流源档上，**DUT 阻抗超过表列最大值时建立时间会显著变长**。
我们测的是虚地（阻抗很低），应当不受影响 —— 但若以后测高阻样品，这条要先查。

---

## 五、两条必须守住的原则

1. **标定用回读值，不用设定值。**
   设定 10.000 pA，实际可能是 10.013 pA。pA 级上这个差不能忽略。
   注：现行脚本更进一步 —— `smu_set()` 还会把**实际选中的档位**查出来记录，
   因为回读的固定误差项（240 fA / 3 pA / 40 pA）随档位变，进不确定度预算要用。

2. **先关输出、再改限压、最后才开输出。**（同上）

---

## 六、未验证的风险（早期遗留，至今仍成立）

- **2636B 直接输出 pA 级电流的准确度**在最低量程上有限度，回读值本身也有
  不确定度。"±1 pA 这个下限是否真的可用"当时就没结论 ——
  要用参考表实测确认，**不要拿数据手册的典型值当结论**。
- 若直接电流源在 pA 级不够稳，常见替代是**电压源 + 高阻电阻**（`I = V/R`）
  产生电流。本项目最终没用这条路（用的是直接电流源），但值得留作备选。

> 被删掉的 `tools/keithley/` 里还有一道 `SAFETY_CEILING_A = 50 nA` 的硬天花板
> （序列里任一点超限就直接拒绝执行，而不是跑一半才发现）。
> **没有移植** —— 因为 `sweep_pulse.py` 的 E1 点峰值是 **1 µA**，是**故意**超的
> （平均值仍在量程内）。一刀切的天花板会误伤脉冲测试。若以后要加，应当只加在
> **直流路径**上，或者做成每点显式声明。

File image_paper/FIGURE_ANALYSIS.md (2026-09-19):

# 逐图数据分析

> 配套 `IMAGE_SPEC.md`（排版规范）与 `FIGURE_NOTES.md`（≤200 字图注）。
> 本文件为分析部分：说明各图的内容、关键数据及其含义。
> 所引数值均由脚本现算，非转录。

---

## 图 1　`fig01_uncal.png`

装置未校准读数对 2636B 回读值的散点，共 162 个电流点，覆盖 ±5~±45 nA、步长
0.5 nA，每点 3 次取均值（已剔除 4 次异常重复）。

散点落成一条直线，与黑色参考线的偏离在图上不易分辨。此即本图所反映的主要事实：
装置相对回读值的偏差为 +1.03%，在 ±45 nA 满量程下相当于 45 nA 处 0.46 nA 的偏移。
参考线的作用在于使该偏移可见；仅有散点时，图形本身不足以支持任何判断。

加入参考线后可观察到，正电流段散点整体位于参考线上方，负电流段位于下方，两段在
零点附近交叉。该形态对应增益性质的偏差：装置对各电流按同一比例读大，约为 1%。
此偏差在重复测量中保持稳定，属确定性成分。

---

## 图 2　`fig02_cal.png`

上格为施加三常数校准后的装置读数对理想线性，下格为同一批 162 个点的残差。

上格中散点与理想线重合，未见可分辨的偏离，表明 +1.03% 的增益误差已被三常数吸收。
有效信息集中在下格：残差围绕零分布，RMS 1.33 pA，最大值 4.12 pA，折合满量程
90 nA 的 0.00458 %FS。

残差量级与校准前的 +1.03% 相差约 225 倍。两个量分属不同范畴：前者为校准前装置
读数相对回读值的准确度，后者为扣除增益与偏置后的形状误差。三常数所能吸收的限于
其参数空间内的成分，残差中剩余者为该空间之外的逐点结构。

---

## 图 3　`fig03_lowI_error.png`

1 pA 至 4 nA 段的测量误差曲线，双对数坐标，共 17 个点。纵轴取误差绝对值；该段误差
在 1~2 nA 之间过零（+0.17% 转为 −0.05%），负值在对数轴上无法表示。

曲线自 1 pA 处的 +65% 单调下降至 4 nA 处的 −0.03%，与 5% 判据线交于 11.1 pA，
即回读值大于 11.1 pA 时相对误差小于 5%。

该交点的成因可由绝对偏差的分布说明。逐点绝对偏差自 0.8 pA 至 4000 pA 基本恒定，
中位 0.538 pA，极差 0.312 至 1.654 pA，与电流大小无显著依赖关系。曲线形态因而与
1/I 双曲线一致，相对误差的上升源于分母减小。5% 交点的位置由该恒定偏置单独决定，
即 0.54 pA ÷ 5% ≈ 11 pA。减小该偏置是使交点左移的唯一途径。

---

## 图 4　`fig04_rel_accuracy.png`

上格为 5~45 nA 段的相对误差绝对值，下格为同批数据的绝对残差，各 162 个点。

下格给出该段的主要特征：绝对残差全程位于 ±2 pA 内，与电流无明显相关（中位
0.824 pA，RMS 1.332 pA）。上格中相对误差自 5 nA 处的 0.036% 降至 45 nA 处的
0.004%，约为 8 倍；其成因为同一绝对误差随电流增大而摊薄，与装置在大电流下的
准确度改善无关。

上格黑色实线即该预期（恒定绝对误差中位值除以电流），实测滚动中位数与之一致，
支持上述解释。散点在同一电流下横跨近两个量级，反映逐点结构，与图 2 下格的残差
同源，属三常数参数空间之外的部分。

---

## 图 5　`fig05_pulse_waveform.png`

四格分别为 A 组（占空比扫描，12 点）、P 组（周期扫描，11 点）、K 组（峰值扫描，
9 点）与直流对照。每组占一条带，蓝色实线为程序设定的输出波形，红色虚线为由装置
读数反推的波形（脉宽与周期相同，峰值取读数除以占空比）。两线的高度差即该点的
读数误差。

A 组峰值 40 nA、周期固定 10 ms，占空比自 50% 降至 2.5%。除 A11 外各点偏差位于
−6.53% 至 +0.47%。A11 的占空比为 2.5%，偏差 −89.72%，反推峰值仅 0.1 nA，对应
装置无法检出该信号。该现象与图 3 同源：平均电流降至 1 nA 量级时，恒定偏置占据
了信号的绝大部分。

P 组占空比固定 25%、周期自 50 ms 降至 1 ms，偏差自 −0.11% 单调恶化至 +4.20%，
与周期缩短相关。脉宽随周期由 12.5 ms 缩至 0.25 ms，表明脉宽较窄时装置响应不足。

K 组平均电流固定 40 nA、峰值自 400 nA 升至 4200 nA，全部落在 −1.10% 至 +0.31%
区间内，为四组中最稳定者。该结果表明峰值大小（远超 ±45 nA 直流量程）对读数无
显著影响，装置响应的是积分电荷。

---

## 图 6　`fig06_lin10_residual.png`

±10 pA 微电流段的残差（装置校准值减回读值）对回读值，22 个点。

偏置呈恒定值 +0.6637 pA，σ 为 0.0437 pA，全程极差 0.1434 pA。正电流 11 点均值
+0.6537 pA，负电流 11 点均值 +0.6736 pA，两者相差 0.02 pA。偏置与电流的大小
及极性均无依赖关系。

该结果与图 3 属同一现象的独立复现。图 3 在 0.8 pA 至 4 nA 段给出恒定偏置约
0.54 pA，本图在 ±10 pA 段给出 0.66 pA；两批数据的时间与量程均不同，量级一致。

纵轴未包含零点：偏置距零为 15σ，零点参考线不提供额外信息，却会使纵轴自零起算，
将 22 个点压缩至顶部狭窄区域。

---

## 图 7 / 8 / 9　三个波长的 I–V 曲线

三张图结构相同，上格为全曲线，下格为零点附近放大并给出线性拟合与 I=0 交点。

| | 546 nm | 436 nm | 365 nm |
|---|---|---|---|
| 点数 | 21 | 30 | 30 |
| 电流范围 | −29 ~ 522 pA | −200 ~ 3770 pA | −220 ~ 5120 pA |
| 高遏止平台 | −28.0 pA | −198.3 pA | −216.7 pA |
| $V_s$（零电流法）| 0.5627 ± 0.0377 V | 1.0510 ± 0.0416 V | 1.5136 ± 0.0343 V |

三个波长的光电流量级相差近 10 倍（365 nm 光子能量最高，光电流最大），反向电流
平台同步放大：546 nm 为 −28 pA，436 与 365 nm 均达 −200 pA 量级。平台对应反向
光电流，即光照射阳极产生的电子被遏止电压加速后形成的电流，其大小随光强变化，
与电压无直接关系。

该平台构成本实验的主要系统误差来源。零电流法以总电流为零为判据，平台电流使该
零点发生偏移。平台绝对值除以该波长的近交点斜率即为偏移量：546 nm 为 0.083 V，
436 nm 为 0.126 V，365 nm 为 0.188 V。三者相差 0.105 V，而 $V_s$ 本身处于 0.56
至 1.51 V 之间，该差异将直接污染斜率。

---

## 图 7 / 8 / 9 交点法版　`*_inter.png`

同样三张图，下格改画交点法的构造：反向电流平台的水平线、线性段的延长线，以及
两者的交点。

线性段的选取为该方法的要点。光电流曲线呈凸性（546 nm 的局部斜率自拐点处
315 pA/V 单调增至远端 1130 pA/V），远端线段的延长线不经过拐点，以其求交将使
$V_s$ 系统偏小；实测采用该窗口会使 $h$ 的偏差由 −6.7% 增至 −25%。

改用交点法后的 $V_s$：

| | 零电流法 | 交点法 | 差 |
|---|---|---|---|
| 546 nm | 0.5627 | 0.6430 | +0.080 |
| 436 nm | 1.0510 | 1.1757 | +0.125 |
| 365 nm | 1.5136 | 1.6989 | +0.185 |

三个波长的修正量分别为 0.080、0.125、0.185 V，与前节算出的平台偏移 0.083、
0.126、0.188 V 基本一致。两条独立路径给出的量相符，可作为交点法适用性的直接证据。

---

## 图 10　`fig10_einstein_plot.png`

遏止电压对频率的直线（零电流法数据），三点带 ±1σ 误差棒及加权拟合。

$h$ = 5.5931×10⁻³⁴ J·s，相对偏差 −15.59%，R² = 0.99997。

R² 在该情形下不具备判别能力。三点接近共线（相邻两点斜率相差 1.89%，
χ²/dof = 0.009），R² 必然接近 1，与斜率是否正确无关。R² 所表征的是线性程度，
而非斜率的准确性：本图与次图的 R² 相差 0.000006，$h$ 相差 9.3 个百分点。论文中
若引用 R²，宜同时说明其含义限于线性。

误差棒 ±0.42% 亦不宜单独引用，其量级为 −15.59% 系统偏差的十五分之一。

---

## 图 11　`fig11_einstein_plot_inter.png`

同一张爱因斯坦直线，改用交点法的 $V_s$。

$h$ = 6.2129×10⁻³⁴ J·s，相对偏差 −6.24%，较零电流法改善 60%。各波长反推逸出功
的极差由 0.1752 eV 收窄至 0.0702 eV。两项独立指标同向改善。

一项自洽性结果：将表观逸出功 $W_{app} = h\nu - eV_s$ 对 $h\nu$ 作图，斜率为
0.0623，与 $h$ 的偏差 6.24% 数值相同。若电压刻度偏小 $\varepsilon$，则 $h$ 的
偏差为 $-\varepsilon$，且 $W_{app}$ 对 $h\nu$ 呈线性、斜率为 $\varepsilon$。
单一刻度因子因而可同时解释 $h$ 偏低与 $W$ 随波长的漂移，两者对应同一误差源。

需要指出，波长刻度误差给出相同的函数形式（$W_{app} = W - \delta h\nu$，斜率
$-\delta$）。三点数据无法区分电压误差与波长误差，增加第四点亦无助于区分，因两者
预测同一条直线。区分二者须对其中一量作独立校准。

剩余 6.24% 的排查宜优先考虑电压标定：电压由单一仪器提供，对应单一刻度因子；
波长误差则要求三个不同标称值的滤光片同时偏离同一比例。但 6.24% 相对数字万用表
的常规指标（约 ±0.5%）偏大，因此存在两种可能：分压链确有问题，或上述模型自洽
而实际误差源另有其处。

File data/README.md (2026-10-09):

# 实测数据归档

> 采集于 **2026-09-13**，固件为 `firmware-v1`（标定那版 = `git show HEAD~n:...`
> 见根 README 的"固件版本"一节）。环境：2636B 源表 + 自制裁板 + CH340 串口。

## 一、标定数据（36 个 `raw_09_13_*.npz`）

**12 个电流点 × 3 次重复**，正负兼备，覆盖 ±2 ~ ±40 nA。

| 点 | 板子读数 | 2636B 回读 | 误差 |
|---|---|---|---|
| +40 | +40.424 | 39.9989 | +1.06% |
| +30 | +30.314 | 29.9987 | +1.05% |
| +20 | +20.196 | 19.9968 | +1.00% |
| +10 | +10.102 | 9.9940 | +1.08% |
| +5 | +5.050 | 4.9940 | +1.12% |
| +2 | +2.016 | 1.9918 | +1.22% |
| −2 | −2.032 | −2.0055 | −1.32% |
| −5 | −5.066 | −5.0060 | −1.20% |
| −10 | −10.124 | −10.0072 | −1.17% |
| −20 | −20.211 | −20.0095 | −1.01% |
| −30 | −30.329 | −30.0110 | −1.06% |
| −40 | −40.434 | −40.0118 | −1.06% |

**注意几个记录上的坑**（都在采集过程中踩到并修正）：

- `--true=` 必须在采集时打对。有 **3 个点事后改过 `true_na`**：`+2`（1.9915→1.9918）、
  `−10`（−10.0070→−10.0072）、`−30`（−30.112→−30.0110，**是把 0 抄成了 1**，
  对应的 3 个 npz 是重采的那一批，旧的一批已删）。
- **2636B 输出全程是开着的**。中途有一次误以为源没开，实际那是输入开路导致的
  假漂移。

## 二、派生结果

| 文件 | 内容 | 生成方式 |
|---|---|---|
| `fit_data.csv` | 36 行，`I_true,c1,c2,m,n` —— 三常数最小二乘的输入 | `scripts/analysis/make_fit_csv.py` |
| `linearity.png` | 图 4-2：未校准输入—输出关系 + 残差（对应 4.3.3） | `scripts/analysis/fit_linearity.py` |
| `residual_fit.png` | 三常数最小二乘的 2×3 图（含残差比例直方图）。RMSE 1.5 pA、N=36 | `scripts/analysis/fit_constants.m` |
| `M3_waveform.png` | M3 高阻↔+5V 交替波形（用于量寄生电容 `C_p`） | 一次性调查 |
| `node_decay_sim.png` | 100 MΩ 输入端节点的电压仿真（判断示波器探头电容的影响） | `scripts/analysis/sim_node_decay.py` |
| `badread_M0.png` | M0（参考断开）整窗：6250 点里**只有 i=0 一个坏读**（值 = 0），及其 ±50 点放大 | 一次性调查 |
| `badread_first_sample.png` | 同上，并排 M0 与 M3（400 点里 31 个坏读）。用于定性"首拍坏读" | 一次性调查 |
| `demo_hist.png` | **原型图**：修正前/修正后两张残差直方图 + 误差曲线 + 输入输出 | 一次性原型 |

> `demo_hist.png` 的用途已被 `scripts/smu/sweep_broad.py` 的 `sweep_broad_fit.png` 取代
> （后者对同一口径做了正式实现），此处只作留档。
>
> 标了"一次性调查/原型"的三张**没有生成脚本**，是当时用临时命令画出来判断问题的。
> 结论已进 `docs/`，图留在这里备查；要重画得照结论重写脚本。

## 二·补、2026-09-15 标定扫描（自动标定第一次跑通）

`cal_sweep_raw.csv` / `cal_sweep_fit.csv` —— 19 点 × 3 次，+45 → −45 nA 步长 5。
**这是本工程第一次跑通自动标定**（之前 36 点数据是手动设源表 + `nanoammeter_capture.py` 采的）。
采集条件：`NPLC=10`、`autozero=ON`、`limitv=5V`。

三常数拟合（MATLAB 与独立 Python 实现结果一致）：

| | 本次 | 旧（09-13） | 差 |
|---|---|---|---|
| `q` | 1.559440e-14 | 1.5546e-14 | +0.31% |
| `I₊` | +49.7153 nA | +49.7172 nA | −0.004% |
| `I₋` | −49.7423 nA | −49.7428 nA | −0.001% |
| RMSE | 1.4093 pA | 1.50 pA | 更好 |
| `cond(A)` | 4.6 | 7.39 | 更好 |

**物理常数复现到 0.3% 以内** → 装置可复现。

未校准准确度：**+1.04% ± 0.04%**（18 个非零点全在 +0.99%~+1.12%），是全域恒定的
纯增益误差，与旧数据的 +1.0~+1.3% 吻合。

### ⚠️ 线性度必须报**样本外**的

> **2026-09-15 更正**：最初报的是 "0.00252 % FS"，那是**样本内残差** —— 拟合用的
> 3 个参数就是照着同一组 57 行调出来的，拿它的残差当线性度是**循环论证**。
> 用户当场指出"标定组和验证组要分开"。

重做（同一批数据，事后拆分即可）：

| 方法 | 样本外 max\|残差\| | 线性度 |
|---|---|---|
| 固定奇偶拆分（标定 10 点 / 验证 9 点） | 3.540 pA | 0.00393 % FS |
| **留一交叉验证（逐点）** | **3.813 pA** | **0.00424 % FS** |
| ~~样本内（作废）~~ | ~~2.266 pA~~ | ~~0.00252 % FS~~ |

**可引用值：线性度 ≈ 0.0042 % FS（≈ 3.8 pA / 90 nA）**，比旧标定 0.0137% 好约 **3.3 倍**
（不是最初说的 5 倍——那个倍数也是样本内的虚高）。

固定拆分那组的残差**随电流单调漂移**（−40 nA 处 −3.5 pA，+40 nA 处 +3.3 pA），
是两组之间约 1e-5 的增益差，属任意拆分的产物；留一验证没有这个趋势，更可信。

零点偏置 0.62 pA。

### 低电流段（< 1 nA）：`cal_lowI_raw.csv` / `cal_lowI_fit.csv`

19 点标定覆盖的是 **±5 nA ~ ±45 nA**（最小非零点 5 nA），**1 pA ~ 5 nA 这一段
原本完全没有数据**，而 `|I| < 1 nA` 时固件自动切到 **10 s 窗口**（`measurement_state.c:115`），
是另一条代码路径。2026-09-15 补测 16 点（1 pA ~ 5 nA，正负兼备）。

**做法**：用 19 点标定定出的常数（**完全没碰低电流数据**）去预测这 16 点 ——
这是**跨电流区间外推**，比随机留一更严格的样本外检验。

```
真值(nA)     残差(pA) 三次            平均
-0.01017   +0.685 +0.461 +0.491     +0.55
 0.00079   +0.671 +0.588 +0.468     +0.58
 0.00181   +0.338 +0.558 +0.729     +0.54
 0.00479   +0.546 +0.579 +0.701     +0.61
 0.00980   +0.725 +0.614 +0.706     +0.68
 0.01983   +0.595 +0.580 +0.524     +0.57
 0.04979   +0.605 +0.615 +0.583     +0.60
 0.09980   +0.709 +0.505 +0.456     +0.56
 0.19982   +0.436 +0.585 +0.467     +0.50
 0.49987   +0.241 +0.138 +0.104     +0.16
```

**结论：从 0.8 pA 到 200 pA，残差是一个恒定的 +0.55 pA，完全不随电流变。**

这说明两件重要的事：

1. **10 s 窗口与 1 s 窗口给出同一套常数。** 式(6) 里 `m+n` 在分母带来的"窗口无关性"
   是**实测成立**的，不是推的 —— 在此之前它只是个理论论证。
2. **那个 +0.55 pA 正是 19 点标定给出的零点偏置（+0.62 pA）**，两套数据同一个偏置，
   不存在"窗口不同导致偏置不同"的问题。

跨区间整体：**RMS 1.066 pA，max 2.83 pA**。

> **1 pA 下限到底能不能用** —— 现在有数据了：**装置在亚 pA 输入下仍线性**，
> 只是被 +0.55 pA 的固定偏置淹没。所以**能不能用取决于要不要减掉这个偏置**：
> 减掉之后，10 pA 以上相对误差好于 6%，100 pA 以上好于 0.7%。
>
> 1 pA 处相对误差仍有 ~20%，但**归因不了**。源表"设定 1 pA / 回读 0.79 pA"差 21%，
> 那是**输出偏差**（设定 vs 回读）—— **不知道是输出偏了还是回读偏了**，要分开得
> 有第三个独立参考。所以**不能写成"那是源表自己的极限、不是装置的"**：
> 那句话拿输出偏差去断言回读的精度，是两回事。见下面「误差口径」。

### 已知弱点：`q` 的标准误偏大

`fit_constants.m` 的杠杆分析：端点项跨度仅 869 pA，计数项 89400 pA，
**杠杆比 103:1** → `M(q)` 相对标准误 **0.073%**，比 `I±` 的 0.001% 大 70 倍。
根因：窗口固定 6250 拍、锯齿周期由电流决定 → 终点相位 = `6250 mod 周期`，
**同一电流重复测相位相同**，重复测量只压噪声、不加端点跨度。

q 的误差是纯增益（进 a），**不影响线性度**。要改善得改用**开环**测量
（固定参考极性 + 灌已知电流 + 让 Δc 跑满斜坡），注意**不能靠"参考断开"**——
`EN=0` 是 Hi-Z 不是 0 A。

---

## 二·补二、误差口径（**三个必须分清的区分**）

> 2026-09-16 加。这三条我在讨论里连续搞混三次，用户逐条纠正后才固化。
> **引用精度数字之前先读这一节。**

### ① 输出偏差 ≠ 回读精度

```
档位      源精度（输出偏差）             回读精度（回读值的精度）
 1 nA     ±(0.15% rdg +  2 pA)        ±(0.15% + 240 fA)
10 nA     ±(0.15% rdg +  5 pA)        ±(0.15% +   3 pA)
100 nA    ±(0.06% rdg + 50 pA)        ±(0.06% +  40 pA)
```

- **输出偏差** = 实际输出对不对得上**设定值** → **与本实验无关**
  （已裁定"以回读值为准"，不用设定值当真值）
- **回读精度** = 回读对不对得上**真实流过的电流** → 只有这一列进不确定度预算

**引数字时必须说清是哪一列**，两列固定项差 1.7~8 倍。

### ② 系统误差被拟合吸收，只有随机误差进残差

校准的"真值"是**回读值**。所以：

- 回读的**系统**误差（例如整体偏高 0.15%）→ **被三常数拟合吸收** →
  **残差里看不见**，它藏在装置的**绝对准确度**里
- 回读的**随机/逐点**误差（噪声、逐点非线性）→ **才进残差**

**所以不能拿"回读的绝对精度"去解释残差。**（曾据此说"8 nA 处回读指标 ±15 pA
→ 残差受参考源限制"，被用户当场指出——那个数里主要是系统项，已被拟合吃掉。）

### ③ 残差是"装置 vs 回读值"之差，不是"装置 vs 真值"

```
残差 = Īₘ(校准后) − Iₛₜd(回读值)
```

**不能写成"装置的准确度"**，报告里必须注明比较基准。

### 实测到的量（2026-09-16）

| 量 | 值 |
|---|---|
| 回读**噪声**（10 nA 连采 40 次） | **σ ≈ 64 fA** |
| 校准后残差（**真验证点**，见下） | 绝对 RMS **1.65 pA**，最大 **3.536 pA** |
| 　正向 / 负向 | RMS **2.08** / **1.05** pA（**正负不对称**） |
| 未校准准确度（≥5 nA） | **+1.04% ± 0.04%**，纯增益 |

**3.5 pA 从哪来：未定。** 已排除：回读噪声（64 fA，小 50 倍）、`Δc` 量化（0.015 pA）、
`T` 的误差（纯增益，被 `q` 吸收）。

### 哪些点算"验证点"

- **标定点本身**（19 点）→ 样本内，**不算**
- **与标定点同电流、但另采一轮的点**（10/15/20/25/30/35/40 nA）→ **伪样本内**
  （装置在给定电流上读数近似确定，重复性 ~1 pA），**也不算**
- **只有插在标定网格中间的真交错点**（6 7 8 9 / 12.5 17.5 22.5 27.5 32.5 37.5 nA）算

（曾把三类混在一张表里报 "RMS 1.69 pA"，被用户抓出。）

### 要验**绝对**准确度，必须换独立参考

现在的基准（2636B 回读）自己也可能有系统偏差，而**它被拟合吃掉了**。
分离的唯一办法：**标准电阻 + 标准电压源（`I = V/R`）**，不确定度可到 0.01% 量级。

---

## 三、关键结论（详见根 README 与 docs/）

- **未校准准确度**：+1.0 ~ +1.3%（纯增益误差 + 约 1.3 pA 偏置）
- **线性度**：0.0137 % FS（≈ 11 pA / 80 nA）—— 比准确度好约 **100 倍**
- **两路 ADC**（内置 vs ADS8866）：斜率差 2 ppm，**换 ADS8866 对准确度没有帮助**
- **三常数拟合**：`q = 1.5546e-14 C/码`、`I₊ = +49.7172 nA`、`I₋ = −49.7428 nA`
  （标准误 0.002%），RMSE 1.50 pA，`cond(A) = 7.39`
- **交叉验证差 1.02%**：由拟合值反推 `R = 100.51 MΩ`，万用表读 99.48 MΩ ——
  差值落在万用表 100 MΩ 档 ±1% 的边缘，在不确定度之内
- **`EN=0` 的 Hi-Z 暂态是真的**：`C_p ≈ 4.9 pF`、`τ ≈ 490 µs`、`Q ≈ 24 pC/次`
  （示波器看到的 ms 级指数衰减主要是**探头自己的 10 pF** 造成的）

## 四、复现

```bash
# 标定点采集（每个已知电流跑一次）
python scripts/smu/nanoammeter_capture.py COM8 --no-noise --true=<nA>

# 汇总成拟合用的 CSV
python scripts/analysis/make_fit_csv.py -d data -o data/fit_data.csv

# 三常数最小二乘
bash scripts/analysis/matlab_utf8.sh "cd('tools'); fit_constants('../data/fit_data.csv')"

# 线性度与图 4-2
python scripts/analysis/fit_linearity.py -d data --plot
```

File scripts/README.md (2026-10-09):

# scripts/ —— PC 端脚本索引

连接仪器、采集、分析、出图的 Python / MATLAB 脚本。**按用途分成五格**：

| 子目录 | 干什么 |
|---|---|
| [`smu/`](smu/) | **2636B 源表控制与采集**（连仪器）|
| [`plotting/`](plotting/) | **绘图**（论文插图）|
| [`analysis/`](analysis/) | 标定、拟合、线性度、误差预算 |
| [`lib/`](lib/) | **公共模块** —— 被上面三者 import，改动要全仓回归 |
| [`misc/`](misc/) | 烧录、副本排查等杂项 |

> ⚠️ **import 约定。** 每个脚本开头有一段 `sys.path` 设置，把 `scripts/` 根 + 各子目录
> （`lib`/`smu`/`plotting`/`analysis`/`misc`）都加进 import 路径，所以脚本之间仍是
> `from cal_sweep import ...` 这样的**平铺 import**。**移动文件或改文件名要全仓回归。**
>
> **一律从仓库根目录运行**（相对路径如 `data/...` 都按仓库根解析）：
> `python scripts/smu/sweep_dense.py ...`

底层依赖：`pyvisa`（源表走 LAN）、`pyserial`、`numpy`、`matplotlib`、`scipy`
（仅 `analysis/outlier_test.py`）。

---

## 一、`lib/` —— 公共模块

被多个脚本 import，**改动要全仓回归**。

| 模块 | 被几个脚本依赖 | 内容 |
|---|---|---|
| `report_table.py` | **9** | 式(6) 的公共实现 `i_of()` + 报告表格（pA/nA、`u_c`、`Δ/u_c`）|
| `cv_linearity.py` | **7** | 物理常数、式(6)、残差与线性度工具 |
| `paper_style.py` | **4** | 论文图的统一风格（配色、字体、`caption()` 定位）|
| `uncal_vs_cal.py` | **3** | 未校准 / 校准后对比（也导图）|
| `dense_report.py` | 2 | 162 点密集标定的交付报告 + 三常数最小二乘 |
| `rel_accuracy.py` | 1 | 相对准确度（`plotting/paper_figs.py` 依赖）|
| `linearity_all.py` | 1 | 全数据拟合线性度 |
| `lowI_error_curve.py` | 1 | 误差-电流曲线（对数横轴）|

（计数由脚本实测，不是估的。）

---

## 二、`smu/` —— 2636B 源表控制与采集

连 Keithley 2636B（走 LAN / pyvisa）做标定与表征，也含串口采集本装置。

| 脚本 | 用途 |
|---|---|
| `cal_sweep.py` | **底层驱动**（串口 + 源表 + 测量原语 `ReadbackSampler`、`MEASURE_TIMEOUT_S`）。也被其它目录 import |
| `sweep_dense.py` | 密集电流网格扫描，**每次测量整窗回传**并存档。`--preset lowI` / `--points` / `--signed` / `--neg-only` / `--pos-only` / `--warm-ms` |
| `sweep_broad.py` | 宽范围扫描 |
| `sweep_dc.py` | 直流扫描 |
| `sweep_iv.py` | 光电探测器 I–V 曲线（A 路源电压 / B 路测电流）|
| `sweep_pulse.py` | 脉冲实验采集（TSP 脉冲源模式）|
| `nanoammeter_capture.py` | **单次采集** → `raw_<日期>_<值>nA.npz/.png/.log`。⚠️ 对 `firmware-v1` 要加 `--no-noise` |
| `test_smu.py` | 源表连通与功能自检 |
| `warm_test.py` | 预热必要性对照实验（always / never / first）|
| `pulse_real.py` | 真实脉冲波形重建（PC 翻转 / 仪器脉冲），含整窗原始码反推 |
| `pulse_probe.py` | TSP 脉冲能力探针；单因素拆分定位三条前置条件 |
| `pulse_introspect.py` | KIPulse 内省（**纯只读**，不开输出、不改状态）|
| `measure_transient.py` | 量 `EN=0` 断开瞬间注入的电荷 → 寄生电容 C_p |
| `switching_times.py` | 开关切换速度与装置各时间尺度 |
| `range_test.py` | 量程效应判定实验（同电流交替 autorange / 锁定）|
| `test_capture.py` | `nanoammeter_capture.py` 的离线回归测试（26 项，不碰串口）|

```bash
python scripts/smu/test_smu.py                              # 先自检源表连得上
python scripts/smu/nanoammeter_capture.py COM8 --no-noise    # 单次采集 ~15 s
python scripts/smu/sweep_dense.py --preset lowI
```

> ⚠️ `cal_sweep.py` 里的 `MEASURE_TIMEOUT_S` 必须**覆盖固件的最长窗口**。长窗
> 2026-09-17 由 10 s 改为 50 s，该常量与 `board_measure`/`board_warmup` 的默认值
> 一并从 40 提到 60。改固件的 `CURRENT_WIN_LONG_TICKS` 时回来一起看。

---

## 三、`plotting/` —— 绘图

把 `data/` 里的实测数据出成论文插图。统一风格见 `lib/paper_style.py`，
正文规范见 [`image_paper/IMAGE_SPEC.md`](../image_paper/IMAGE_SPEC.md)。

| 脚本 | 出什么 |
|---|---|
| `paper_figs.py` | 低电流段图（读 `data/lowI_pos/raw.csv`）|
| `paper_lin10_fig.py` | ±10 nA 那批的图 |
| `paper_pulse_fig.py` | 脉冲四格图（A/P/K/直流对照）|
| `photoelectric_fig.py` | 光电效应相关图 |
| `photo_data_fig.py` | 光电数据图 |
| `dark_current_fig.py` | 暗电流图（数据来自 `smu/sweep_iv.py`）|
| `residual_pct_plot.py` | ±5~45 nA 残差百分比图（`--bar` 出分组柱状图）|
| `console_figure.py` | **网页控制台截图**（注入真实测量数据后 Chrome headless 渲染）|

```bash
python scripts/plotting/paper_figs.py
python scripts/plotting/console_figure.py            # 深色版
python scripts/plotting/console_figure.py --light    # 浅色版（白底论文用）
```

> ⚠️ `console_figure.py` 截图前**不要开页面直接截** —— 空白的控制台只有布局没有内容。

---

## 四、`analysis/` —— 标定与分析

标定常数拟合、线性度、误差预算、脉冲分析。

| 脚本 | 用途 |
|---|---|
| `fit_constants.m` / `make_fit_csv.py` | 三常数（`M`/`I₊`/`I₋`）最小二乘拟合 + 汇总 CSV |
| `fit_linearity.py` / `fit_tau.py` | 早期拟合链 |
| `cal_table.py` | 逐点标定表 |
| `detect_limit.py` | 检测下限 |
| `lowI_compare.py` | 三条误差链：装置 / 设定 / 2636B 回读 |
| `outlier_test.py` / `.m` | 独立性检验与离群值判定（Python / MATLAB 双实现互校）|
| `reproducibility.py` | 残差是"电流的确定函数"还是"每轮随机"—— 跨轮复现性 |
| `seg0_budget.py` / `seg0_joint_fit.py` | 低电流段（段0）偏置拆项、并进拟合 |
| `fsw_hypothesis.py` | 「段0 偏置 = 锯齿轮翻转电荷注入」形状预测检验（已证伪）|
| `endpoint_codes.py` | 8 / 9 nA 两点的 ADC 端点码差 Δc |
| `range_effect.py` | 自动量程切换的影响（跨档外推法）|
| `window_sawtooth.py` | 窗口内锯齿波形态 |
| `raw_recalc.py` | 结果行 RAW 段代回式(6)，绕过屏幕取整 |
| `analyze_pulse.py` | 脉冲实验分析（方案见 `docs/脉冲电流实验方案.md`）|
| `sim_pulse_recover.py` | 脉冲恢复仿真 |
| `sim_node_decay.py` | 仿真 100 MΩ 输入端节点电压波形 |
| `wave_compress.py` | 整窗波形能压多少（用实测数据量，不猜）|
| `test_make_fit_csv.py` / `test_fit_constants.m` | 上面拟合链的回归测试 |
| `matlab_utf8.sh` | 在 MATLAB 里跑 `.m`（中文注释不乱码）|

```bash
# 对每个已知电流采一次 → 汇总 → 拟合
python scripts/smu/nanoammeter_capture.py COM7 --no-noise --true=25.0
python scripts/analysis/make_fit_csv.py -d . -o fit_data.csv
bash  scripts/analysis/matlab_utf8.sh "cd('scripts/analysis'); fit_constants('../../fit_data.csv')"
```

> 拟合的物理推导见 [`docs/校准方案推导.md`](../docs/校准方案推导.md)，
> 面向初学者的操作步骤见 [`docs/拟合操作指南.md`](../docs/拟合操作指南.md)。

---

## 五、`misc/` —— 杂项

| 脚本 | 用途 |
|---|---|
| `uart_flash.py` / `boot0_probe.py` | 串口 bootloader 烧录路径（独立于 ST-Link）。⚠️ 固定 115200 8E1，**不要改** |
| `console_copies.py` | 列出各控制台副本及版本，判断你打开的是哪一份 |
| `run_app.sh` | 用 SWD 把 PC 灌进 app 的 Reset_Handler（绕开"复位进 ROM bootloader"）|

`run_app.sh` / `boot0_probe.py` 里的 openocd 默认为 PATH 上的 `openocd`，
自定义安装用环境变量 `OPENOCD` / `OPENOCD_SCRIPTS` / `OPENOCD_CWD` 覆盖。

---

## 六、几条踩过的坑

- **CSV 硬约束**：表头只用英文、数值只用十进制整数、**不得有 BOM**、无注释行、换行 `\n`
  —— 中文 Windows 上 MATLAB 与 Origin 对 UTF-8 处理不一致。
- **单位坑**：`ReadbackSampler` 给的是安培，而所有 CSV 的 `true_nA` 是纳安。差 1e9，踩过多次。
- **聚合口径**：逐点均值 vs 逐次，两者差 1.3 倍，混用会得出不同结论。
- **等待上限要跟着窗口走**：跟不上就会出现"预热: 无响应"那类假故障（2026-09-16 撞过）。
- **改控制台要同步**：仓库里那份在 `pc-console/console.html` 是源头；桌面交付目录、release、
  backup 各有一份副本。改了不生效先用 `misc/console_copies.py` 查你打开的是哪份。

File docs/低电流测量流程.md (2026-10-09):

# 低电流段（1 pA ~ 4 nA）测量流程

> 2026-09-16 写。给"晚上自己跑一遍"用，所以**按顺序抄命令即可**，每步都有
> 判据和"不对时怎么办"。

## 前提

| 项 | 怎么确认 |
|---|---|
| 2636B 通 | `ping 192.168.0.2`，或直接跑下面第 0 步 |
| CH340 通 | **别写死 COM 号** —— **插拔 USB 会让它重新枚举**（本会话里见过 COM9→COM6；另外两次"消失"是人为拔线，不是故障）|
| 固件常数 | 应该是 `CAL Q 15596,49712,-49739`（09-16 写入的 162 点拟合值）|

```bash
cd C:\Users\40512\STM32Toolchain\nanoammeter_repo

# 第 0 步：确认端口（拿到 COM 号再往下）
python -c "import serial.tools.list_ports as l; print([p.device for p in l.comports() if p.vid==0x1A86])"

# 确认固件里的常数（把 COM6 换成上一步拿到的）
python -c "
import sys; sys.path.insert(0,'tools')
from cal_sweep import board_open
s=board_open('COM6',115200); s.write(b'Q\n'); print(s.readline().decode(errors='replace')); s.close()"
# 期望: CAL Q 15596,49712,-49739
```

---

## 第 1 步（可选）：预热验证（约 8 分钟）

**这一步只值 13 分钟** —— 低电流段每个点要 4 次 50 s 测量（3 次正式 + 1 次预热），
若预热能走 1 s 短窗，整批省 13 分钟。**但"预热效果与窗口长度无关"这个假设
从没验证过**，而且有反向证据（09-16 冒烟测试里 +20 nA 的预热返回了 TIMEOUT）。

**想省时间可以整步跳过**，第 2 步不加 `--warm-ms` 即可（那是安全默认，
只是慢 13 分钟）。要跑的话：

```bash
python scripts/smu/warm_test.py --visa "TCPIP0::192.168.0.2::5025::SOCKET" --port COM6 \
       --points 20,2000 --rounds 3 --n 3 --win-ms 50000 --win-below-pa 20
```

⚠️ `--win-ms 50000 --win-below-pa 20` 必须加 —— 否则 20 pA 那个点走的是固件
自动的 10 s 窗，测的就不是第 2 步实际用的窗口了。

**判据（脚本自己会打印结论）**：三条都没系统差别 → 预热可以砍。
- "可以砍" → 第 2 步加 `--warm-ms 1000`
- "要保留" → 第 2 步**不加**

---

## 第 2 步：低电流分级扫描（**分正负两批**，每批约 27 分钟）

**2026-09-16 起分两批跑，不再一次扫正负。** 原因：正负两侧的段0偏置要**分开
定标**（正向实测 +0.511 pA，负向还没有数），而一次 `--both` 会跑 102 次、
一个多小时，中途断了正负两边都只有半截，没法单独出一批的结论。

正向（**已完成**，51 次，实跑 26.6 分钟）：

```bash
python -u scripts/smu/sweep_dense.py \
  --visa "TCPIP0::192.168.0.2::5025::SOCKET" --port COM9 \
  --preset lowI --pos-only --warm-ms 1000 \
  --out data/lowI_pos > data/lowI_pos_run.log 2>&1
```

负向（第 2 步之二，命令只差 `--neg-only` 与 `--out`）：

```bash
python -u scripts/smu/sweep_dense.py \
  --visa "TCPIP0::192.168.0.2::5025::SOCKET" --port COM9 \
  --preset lowI --neg-only --warm-ms 1000 \
  --out data/lowI_neg > data/lowI_neg_run.log 2>&1
```

⚠️ **`--neg-only` 是 09-16 新加的。** 原来只有 `--pos-only`，要只扫负向就得把
整张点表逐个加负号手打一遍。点表一律写**幅值**，开关负责整条镜像。
负向批次按**幅值从小到大**（−1 pA → −4 nA），与正向批次同序 ——
两批的第 k 个点落在同一段测量时间内，事后比漂移才对得齐。

⚠️ `--port` **必须按第 0 步当时拿到的号写**。CH340 插拔后号会变
（09-16 正向那批是 COM6，现在这台是 COM9）。不写也行 —— `board_open()`
会按 VID:PID `1A86:7523` 自动找；但**写死一个过时的号会直接报"找不到 CH340"**。

**`--warm-ms 1000` 的依据**：正向那批已经用这个配置跑完且预热行正常
（不是"无响应"），所以负向沿用同一配置，两批可直接比。若第 1 步的
`warm_test.py` 说"预热不能砍"，则两批都**不加** `--warm-ms`。

### 时间分配（正向那批实测，51 次 / 26.6 分钟）

| 段 | 点数 | 每次测量 | 小计 | 占比 |
|---|---|---|---|---|
| 1~20 pA（强制 50 s 窗）| 8 | 50 s | 1135 s | **71%** |
| 30~500 pA（自动 10 s 窗）| 6 | 10 s | 207 s | 13% |
| 1~4 nA（自动 1 s 窗）| 3 | 1 s | 22 s | 1.4% |
| 换点整定 | 17 | 3 s | 178 s | 11% |
| 预热（1 s 短窗）| 17 | 3 s | 52 s | 3.3% |

**结论：整批时间几乎全花在最低那 8 个点上**（每个 50 s × 3 次）。
测量段里 **96% 是纯积分窗口**，波形回传只占 4%（115200 bps 下 1.09 s/次）。
所以**想缩短只能动窗口长度或重复次数，改波特率没用**。

开跑后**先盯一眼日志**，确认预热正常：

```
──  +0.0010 nA  (1/102)
   窗口: WIN 50000ms (312500 ticks)     <- 固件接受了 50 s 窗口
    预热: +0.0009                        <- 正常
```

**若出现 `预热: 无响应`** → 预热的超时没跟着窗口走，等于没预热、还白等 40 秒。
（这个 bug 09-16 在真机上撞到过一次，已修，但**修完没在真机上验证过** —— 
第一次跑必须看这一行。）

`--preset lowI` 展开成：

```
点表: 1 2 4 6 8 10 15 20 | 30 50 100 200 300 500 | 1000 2000 4000  pA
      └── 强制 50 s 窗口 ──┘ └─ 固件自动 10 s ──┘ └─ 固件自动 1 s ─┘
```

17 个值 × 3 次 = **51 次测量/批**；正负两批共 102 次、约 53 分钟。

**为什么是分级而不是均匀步长**：用户提过"统一 50 s + 每 20 pA 一点"，算下来
**29.7 小时**，而且**低端只拿到 1 个点**（1 pA 起，下一个就 21 pA），249 个点
全挤在 1~5 nA 段 —— 疏密放反了。低端恰恰是最难、09-15 实测出过问题的地方。
分级之后低端点数从 1 个变 8 个，时间降到 51 分钟。

**中断不怕**：每行测量立刻落盘（`data/lowI_neg/raw.csv` + `w_*.npz`），重跑同一条
命令会**自动跳过已完成的点**。所以断了直接再跑一次。

**进度怎么看**：`ls data/lowI_neg/*.npz | wc -l`（总数 51）。

---

## 第 3 步：出报告

```bash
python scripts/lib/dense_report.py --dir data/lowI_neg --fs-na 8 \
  -o data/lowI_neg_residual.png --out-ac data/lowI_neg_autocorr.png
```

⚠️ **`--out-ac` 也要给**。它默认写 `data/dense_autocorr.png`，不给就盖掉高电流段那张。

⚠️ `--fs-na` 要跟着改：低电流段满量程是 4 nA，所以是 **8 nA**（±4），
不是高电流段的 90 nA。**不改的话 `%FS` 会小 11 倍。**
负向那批同样填 **8**（取幅值，别填 −8 —— 残差是带符号的，填负号会把
`%FS` 的符号整个翻过去）。

输出两栏：

- `data/lowI_neg_residual.png` —— δ(I) 形状
- `data/lowI_neg_autocorr.png` —— 自相关（决定能不能插值修正）

### 3b. 段0 偏置的三张表/图

```bash
# 报告格式表格 (pA 为单位, 含 u_c 与 Δ/u_c)
python scripts/lib/report_table.py --dir data/lowI_neg

# 三条误差链: 装置 / 设定 / 回读 —— **看正负两侧的偏置符号是否一致**
python scripts/analysis/lowI_compare.py --dir data/lowI_neg --panel rel --logy

# 误差-电流曲线 (对数横轴, 横轴取 |I_std|)
python scripts/lib/lowI_error_curve.py --dir data/lowI_neg
```

⚠️ 这三个脚本的输出文件名**已按数据目录自动加前缀**（`data/lowI_neg_compare_rel_logy.png`
等等）。09-16 之前是写死的 `data/lowI_compare.png`，跑负向批会把正向的图**盖掉**。

⚠️ `report_table.py` 的 `--syst-pa` 默认 **0.072 pA，那是正向段的**逐点结构。
负向段要等这批数据出来后才能定，**在那之前不要拿负向表的 `u_c` 去比 `Δ/u_c`**。

---

## 排障

| 症状 | 原因 / 处理 |
|---|---|
| `could not open port 'COMx'` | USB 被拔了、或插拔后换了号。重跑第 0 步拿新号 |
| `装置无响应 (试过 115200/921600)` | 同上；也检查板子供电 |
| 报告里 `%FS` 大得离谱 | `--fs-na` 忘改（低电流段是 8，不是 90）|
| 报告里某一个点残差几百 pA | 数据质量闸门没滤干净 —— `dense_report.py` 里有两个闸门（源侧 1% + 5σ 裁剪），看看打印出来丢了哪几条 |
| 测量大面积 TIMEOUT | 检查回路；`E` 指令的 `PRE=` 若不为 0 说明拉回相超时 |

---

## 这批数据能回答什么

1. **低电流段标定后的残差水平** —— 之前只有 09-15 的 19 点、而且和 <1 nA 那批
   混在一起报过，口径不清
1b. **段0 的偏置在正负两侧符号是否相同** —— 正向实测是 **+0.511 ± 0.072 pA**
   （1 pA~500 pA 全段恒定，50 s 与 10 s 窗都一样）。负向这批就是来回答
   "它是**固定正向偏置**（负向也报 +0.5 pA）、还是**随极性翻转**（负向报 −0.5 pA）"。
   两者的物理含义完全不同：前者是单方向的固定注入（开关电荷注入没被排除干净），
   后者更像零点定义偏了一个码。**这是负向那批最主要的目的。**
2. **δ(I) 在低端平不平滑** —— 决定"能不能用查表插值修残差"。高电流段（±5~45 nA）
   已经测过，答案是**不平滑**（lag-1 ρ = +0.027）；低端**还没测过**
3. **1 pA 到底能不能用** —— 09-15 实测 1 pA 读 −100%、4 pA 读 −47.9%，样本
   只有 2 个点。这批有 8 个低端点，能看清
4. **零点附近的行为** —— 拟合有自由常数项，任何**常数**偏置都会被吸收；所以
   低端若出现"减不掉的偏移"，说明它**不是常数**，那就值得追

## 已知的口径坑（引用数字前必读）

- **残差 = 装置 vs 2636B 回读值**，不是 vs 真值。回读的系统误差被三常数拟合
  吸收，**残差里看不见** → 绝对准确度不可知，要换独立参考
- **`%FS` 的分母要跟着量程改**
- **逐点均值 vs 逐次** 是两个口径，差 1.3 倍，混用会得出不同结论
- 低电流段用 50 s 窗口，**与高电流段的 1 s 窗口不是同一条代码路径** ——
  两段数字不能直接比

详见 `data/README.md` 的「误差口径」一节。

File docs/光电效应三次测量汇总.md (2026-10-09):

# 光电效应三次测量汇总（546 / 436 / 365 nm）

> 数据：2026-09-17 用户直接给出（仓库里没有光电效应的原始记录，本文件是首次成档）。
> 原始点已存 `data/photoelectric_raw.csv`（81 行，列：`lambda_nm, block, V, I_nA`）。
> 复现：`python scripts/plotting/photoelectric_fig.py`

---

## 一、数据概况

| λ / nm | 点数 | 电压范围 / V | 电流范围 / pA | 高遏止平台 / pA | 细扫点数 | 细扫斜率 / (pA/V) | 细扫 R² |
|---|---|---|---|---|---|---|---|
| 546 | 21 | −1.103 ~ +0.010 | −29 ~ 522 | −28.0（4 点） | 5 | 348.6 | 0.9934 |
| 436 | 30 | −1.997 ~ +0.001 | −200 ~ 3770 | −198.3（6 点） | 10 | 1590.4 | 0.9937 |
| 365 | 30 | −1.949 ~ +0.001 | −220 ~ 5120 | −216.7（3 点） | 9 | 1168.9 | 0.9982 |

| λ / nm | ν / 10¹⁴ Hz | hν / eV |
|---|---|---|
| 546 | 5.49070 | 2.2708 |
| 436 | 6.87597 | 2.8437 |
| 365 | 8.21349 | 3.3968 |

> 平台按**统一规则**取：最负端起、|I − I_首| ≤ max(2 pA, 5 %·|I_首|) 的最长前缀。
> 细扫段是实验者判断"这段是直的"才加密扫的，交点法的线性段就用它。

---

## 二、遏止电压与逸出功

| λ / nm | $V_s$ 零电流法 / V | $W$ / eV | $V_s$ 交点法 / V | $W$ / eV |
|---|---|---|---|---|
| 546 | 0.5627 ± 0.0377 | 1.7080 | 0.6430 | **1.6277** |
| 436 | 1.0510 ± 0.0416 | 1.7926 | 1.1757 | **1.6679** |
| 365 | 1.5136 ± 0.0343 | 1.8832 | 1.6989 | **1.6979** |

**$W$ 应当与波长无关**（接触电势差只平移截距、不改斜率）。两种方法的 $W$ 极差：

- 零电流法：**0.1752 eV**
- 交点法：**0.0702 eV** ← 好 2.5 倍

---

## 三、普朗克常数

| 方法 | 斜率 $a$ / (V·s) | R² | $h$ / (J·s) | 相对偏差 | $W$ 极差 |
|---|---|---|---|---|---|
| 零电流法 | 3.4924e−15 | 0.99996956 | 5.5954e−34 | −15.55 % | 0.1752 eV |
| **交点法** | 3.8778e−15 | 0.99997571 | **6.2129e−34** | **−6.24 %** | 0.0702 eV |

真值 $h_0$ = 6.62607015e−34 J·s。**可引用值：$h$ = 6.2129e−34 J·s，偏差 −6.24 %。**

---

## 四、三条必须写进正文的话

### ① R² 在这里是误导性的，不能当质量证据

两种方法的 R² 只差 **0.000006**，而 $h$ 差了 **9.3 个百分点**；残差 RMS 甚至**同为 0.0021 V**。

**R² 只测"直不直"，不测"斜率对不对"。** 六个点老实排在一条直线上，只是这条线的斜率整体偏小，R² 对此毫无感觉。（同一条教训见 `scripts/analysis/fit_linearity.py` 开头。）

论文里若提 R²，**必须同时说明它只表征线性、不表征准确度**。

### ② 剩余 6.24 % 是尺度/系统误差，不是散点

把 $W_{app} = h\nu - eV_s$ 对 $h\nu$ 作图，斜率 **0.0623 = 6.23 %**，与 $h$ 的偏差**完全相等**。
这不是巧合：若电压刻度偏小 $\varepsilon$，

$$V_s^{meas} = (1-\varepsilon)V_s^{true} \Rightarrow h_{app} = (1-\varepsilon)h,\quad W_{app} = \varepsilon h\nu + (1-\varepsilon)W$$

**一个刻度因子同时解释 h 偏低与 W 漂移** —— 两者是同一个问题的两面。

⚠️ 但**波长刻度误差**给出完全相同的签名（$W_{app} = W - \delta h\nu$，斜率 $-\delta$）。
**三点分辨不出**是电压还是波长，**加第四点也分辨不出**（两者都预测同一条直线）。
**只有独立校准其中一个量才能破简并。** 物理上电压更可疑：一台仪器、一个刻度因子。

> 另注：6.24 % 对数字万用表而言过大（一般 ±0.5 %），故要么分压链确有问题，要么模型自洽但真因在别处。

### ③ 再加波长的收益

| 加哪个 | $S_{xx}$ | $\sigma_k$ 改善 |
|---|---|---|
| （现有 3 点） | 3.707 | — |
| +404.7 nm | 3.932 | 3 %（几乎没用，与 365/436 挤同段）|
| +577.0 nm | 5.785 | **20 %**（红端，杠杆最大）|

**对 6.24 % 毫无帮助** —— 它是系统误差，$\sigma_h$ 从 0.42 % 降到 0.34 % 不影响结论（差 18 倍）。
若仍要测一个，**选 577 nm**。

---

## 五、暗电流（另测，2026-09-17 部分）

| V / V | I / pA |
|---|---|
| −1.995 | 0.700 |
| −1.799 | 0.780 |
| −1.700 | 0.810 |
| −1.600 | 0.810 |
| −1.499 | 0.830 |
| −1.401 | 0.860 |
| −1.300 | 0.880 |

- **符号相反**：暗电流 **+0.70~0.88 pA**，而反向电流平台是 **−28 ~ −220 pA**（大 35~270 倍）
  → **平台不是暗电流**，平台是**反向光电流**（光打阳极，遏止电压加速它，止不住）
- 扣掉暗电流对 $V_s$ 的影响 ≤ **2.3 mV**，远小于 ±35~42 mV 的不确定度 → **交点法不需要暗电流修正**
- 顺带：暗电流均值 0.810 pA ≈ 装置自身零点偏置 0.664 pA（另一实验测得）
  → 扣掉后**管子本身的暗电流只有 0.15 pA**

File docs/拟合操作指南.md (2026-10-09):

# 用 MATLAB 拟合物理常数 —— 操作指南

> 面向 MATLAB 初学者。从**测数据**到**把结果发给固件**，一步不落。

## 你要做的事（一句话）

测一串**已知电流**，让 MATLAB 反推出式(6) 里的三个常数：`M`（含电平移位增益的
等效电容）、`I₊`、`I₋`。

$$
I=\frac{M\,(V_{o1}-V_{o2})}{(m+n)\,T}-\frac{m\,I_{+}+n\,I_{-}}{m+n}
$$

---

## 开始之前，先确认三件事

| | |
|---|---|
| MATLAB 装了 | 打开能看见窗口就行 |
| 板子烧了 `firmware-v1` | 结果行要带 `RAW` 段 |
| 有一个能给出**已知电流**的源 | 源表，或者"电压 ÷ 高阻" |

> ⚠️ **已知电流必须 ≥ 1 nA。** 式(6) 是模式一的公式；低于 1 nA 固件会自动切到
> 小电流模式，那条路**不出 `RAW` 段**，采了也用不上。

---

## 第一步：采数据（每个已知电流跑一次）

打开命令提示符 / Git Bash，进到仓库目录，然后：

```bash
python scripts/smu/nanoammeter_capture.py COM7 --no-noise --true=25.0
```

三个参数的意义：

| 写法 | 换成 |
|---|---|
| `COM7` | **你的串口**。不确定就跑 `python -c "import serial.tools.list_ports as p; print([x.device for x in p.comports()])"` |
| `--no-noise` | 保持写。`firmware-v1` 没有底噪指令，不加这个会干等 90 秒然后失败 |
| `--true=25.0` | **这次输入电流的已知真值，单位 nA** |

> **`--true=` 必须写成等号形式。** 写成 `--true -40` 的话，那个 `-40` 会被当成
> 串口名。负数尤其要注意。

跑完当前目录会多出 `raw_日期_值nA.npz`、`.png`、`.log` 三个文件。

**每个已知电流跑一次。** 建议：

- **正负都要有** —— 只有同号的数据，`I₊` 和 `I₋` 分不开
- **跨整个量程** —— 1 nA 到 45 nA 都覆盖到
- **每个量程几十组** —— 太少的话拟合结果不稳

---

## 第二步：汇总成 CSV

```bash
python scripts/analysis/make_fit_csv.py -d . -o fit_data.csv
```

它会打印：

```
写入 C:\...\fit_data.csv : 12 行 (端点码用 ADS8866 外部 那一路)

  文件                                     I_true(nA)      m+n    c2-c1
  raw_09_13_+25.0nA.npz                       25.0000     6250     -312
  raw_09_13_-40.0nA.npz                      -40.0000     6250      108
  ...

跳过 2 个:
  raw_09_13_old.npz                          没有 RAW 段 (老固件?)
  raw_09_13_+5.0nA.npz                       没记已知真值 (采的时候没加 --true=)
```

**逐行核对这张表。** 如果看到"没记已知真值"，说明那几次采集忘了加 `--true=`，
得重采。

**这一步绝对不要手工抄。** 每个文件要取 4 个数、还要和当时的已知电流严格配对，
抄错一行整条拟合就歪了，而且**歪得不明显**。

---

## 第三步：在 MATLAB 里跑

### 方式 A：图形界面（推荐初学者）

1. 双击打开 MATLAB（**首次启动要 30~60 秒**，正常）
2. 看左边「当前文件夹」那一栏，点进去，导航到 `nanoammeter_repo\tools`
3. 看下方「命令行窗口」，`>>` 后面**输入这一行，回车**：

```matlab
fit_constants('C:\完整路径\fit_data.csv')
```

> 路径要写**完整的**。偷懒的办法：在资源管理器里按住 Shift 右键点那个 CSV，
> 选「复制文件地址」，粘贴进来，把首尾的引号留好。

### 方式 B：命令行（不进图形界面）

在仓库根目录：

```bash
bash scripts/analysis/matlab_utf8.sh "cd('scripts/analysis'); fit_constants('../../fit_data.csv')"
```

### 先跑一遍自测（可选，但推荐）

想确认脚本本身没坏，跑这个（用合成数据，**不需要任何硬件**）：

```bash
bash scripts/analysis/matlab_utf8.sh "cd('scripts/analysis'); test_fit_constants"
```

看到 `############ 全部通过 ############` 就对了。

---

## 第四步：读输出

```
===== 拟合结果 (n=12 组) =====
  M    = +3.005319e-10  ± 1.4e-12   (0.452%)   期望 |M| ≈ 3.030e-10
  I-   = -50.2551 nA  ± 0.0002 nA  (0.000%)   独立实测 -50.2550 nA
  I+   = +50.2320 nA  ± 0.0002 nA  (0.000%)   独立实测 +50.2320 nA
  RMSE = 1.0676 pA
  条件数 cond(A) = 20

  ---- 杠杆对比 (决定各自能被定到多准) ----
    端点项 M·a1  的跨度 =    62.61 pA
    计数项 b2·a2 的跨度 = 59986.73 pA
```

| 看什么 | 怎么判断 |
|---|---|
| **`±` 后面的标准误** | **这个才是重点**。误差 0.03% 就是"这个数只准到这个程度" |
| **`期望 \|M\| ≈ 3.030e-10`** | 拟合值应在它附近。差一个数量级（比如 3.3e-11）说明 CSV 里的码列取错了 —— 那正好是把电平移位增益除反的样子 |
| **`独立实测`** | 和 `V/R` 量的值对照。**对不上说明模型或数据有问题** |
| **`RMSE`** | 应和仪器的分辨力同量级（模式一约 1 pA）。远大于 1 pA 说明数据有离群点 |
| **`条件数`** | 大于 100 会**自动报警** —— 数据覆盖太窄或全是同号 |
| **`杠杆对比`** | 见下 |

### 杠杆对比：两个参数的可信度不一样

```
计数项跨度   60 nA   -> I+/I- 的杠杆
端点项跨度  ???      -> M(q) 的杠杆 —— 取决于你的数据
```

**计数项的杠杆是实验设计保证的**：只要你的已知电流跨量程、正负都有，
占空比就必然大范围变化，`I₊`/`I₋` 一定定得准。

**端点项的杠杆则不一定**。因为窗口长度固定 6250 拍、锯齿周期由电流决定，
终点相位 = `6250 mod 周期(电流)` —— **同一个电流重复测，相位每次都一样**，
重复只能压低噪声、不能增加跨度。极端情况下 `Δc` 几乎不变，
`M` 就**完全定不出来**（脚本会因条件数 1e17 报警）。

**所以：**

| 量 | 怎么办 |
|---|---|
| `I₊`/`I₋` | ✅ 直接用拟合结果 |
| `q` | ⚠️ **先看杠杆**：`fit_constants.m` 会用**你的实测数据**把杠杆算出来打印。铺满大半个摆幅就可以用；很窄就去测开环 |

**先量，不要猜。** 你也可以在 `make_fit_csv.py` 打印的表里直接看 `c2-c1` 那一列
的跨度，心里先有个数。

**开环测量**（需要 `q` 更准时）：固定参考极性、灌入已知电流、让 `Δc` 跑满整条
斜坡，`q = I·T/Δc`，重复 N 次再降 `√N`。

> ⚠️ **开环也不能靠"参考断开"来做** —— `EN=0` 是 Hi-Z 不是 0 A，
> 那个浮空节点会注入一个指数衰减的暂态电荷（`C_p=10pF` 时误差 12.5%）。

### 自动弹出的四张图

| 图 | 看什么 |
|---|---|
| 左上 拟合 vs 已知 | 点应贴着 45° 虚线。**在小电流那头散开是正常的**（分辨力限制） |
| 右上 残差 | 应围绕 0 随机散布，**不能有喇叭形或弯曲** |
| 左下 相对残差 | 小电流处偏大是正常的（相对误差本来就大） |
| 右下 拟合出的参考电流 | 两根柱应差不多高（±50 nA 附近） |

**残差图出现喇叭形或弯曲 = 模型有问题，别急着用结果。**

---

## 第五步：把结果发给固件

脚本结尾会直接给出一行现成的指令：

```
      Q15133,50232,-50255
```

**这一行直接发给板子**（用网页控制台，或任意串口终端），固件会回：

```
CAL Q SET 15133,50232,-50255
```

就存进 Flash 了，**掉电不丢**。想确认，发一个裸 `Q` 查询：

```
CAL Q 15133,50232,-50255
```

> `q` 这一项如果是用上面说的**专门测量**得到的，就把那次的数字替换掉 `Q` 里的
> 第一个数，其余不变。

---

## 常见错误

| 报错 | 原因 |
|---|---|
| `未定义函数或变量 'fit_constants'` | 当前文件夹没在 `tools` 里。用 `cd` 过去，或者把 `tools` 加进路径 |
| `fit_constants:col 缺列 xxx` | CSV 表头不对。应该正好是 `I_true,c1,c2,m,n` |
| `fit_constants:code c1 超出 16 位码域` | CSV 里混进了别的列，或者分隔符被 Excel 改过 |
| `!! 条件数偏大` | 数据覆盖太窄 / 全是同号。补测几组 |
| 中文显示成方块 | MATLAB 主页 → 预设 → 字体，换一个支持中文的字体 |
| 命令窗口输出乱码（用 `-batch` 重定向时） | Windows 下 MATLAB 输出是 GBK，用记事本打开，或 `iconv -f gbk -t utf-8` |

---

## 为什么值得这么做（而不是用老的 a/b 分段拟合）

| | `a/b` 分段拟合 | 拟合物量参数 |
|---|---|---|
| 参数个数 | 3 段 × 2 = **6 个** | **3 个，全量程共用** |
| 参数含义 | 经验增益/偏置，黑盒 | **物理量，能和独立测量对照** |
| 段与段之间 | 各自为政，接缝处跳变 | 自然连续 |

拟合出来的 `I₊`、`I₋` **每一个都能用万用表独立验证** —— 对不上就说明有问题。
`a/b` 做不到这一点。

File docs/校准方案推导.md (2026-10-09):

# 校准方案的推导与实现

> 本文记录式(6) 的常数校准方案：**参数如何从 7 个标称值塌缩到 3 个待测量**、
> **为什么不同的量必须用不同的求解方法**、以及**实现时的数值与工程考量**。
> 可直接作为报告「校准」一节的素材。

---

## 1. 问题的提出

电荷平衡法的测量式（论文式(6)）：

$$
I=\frac{C\,(V_{o1}-V_{o2})}{(m+n)\,T}-\frac{m\,I_{-}+n\,I_{+}}{m+n}
$$

其中 $m$、$n$ 分别是积分斜率 $>0$、$<0$ 的周期数，$T$ 为单个积分周期。
把每个参量的物理来源拆开：

| 参量 | 来源 | 标称值 |
|---|---|---|
| $C$ | 积分电容 | 100 pF |
| $V_{o1},V_{o2}$ | **不直接测**，由 ADC 码经电平移位反推 | — |
| $T$ | TIM6 周期：$80\,\text{MHz}/(79{+}1)\times160$ | 160 µs |
| $I_{+},I_{-}$ | $\pm5\,\text{V}$ 经 100 MΩ | ±50 nA |

$V_o$ 的反推链（OPA735 反相求和器 + ADS8866）：

$$
V_{\text{ad}}=1.55-0.33\,V_o
\quad\Longrightarrow\quad
V_o=\frac{1.55-c\cdot\frac{3.3}{65536}}{0.33}
$$

**统计一下标称值：$C$、$3.3\,\text{V}$、$0.33$、$1.55\,\text{V}$、$\pm5\,\text{V}$、
$100\,\text{M}\Omega$、$160\,\mu\text{s}$ —— 共 7 个，且没有一个被测过。**

---

## 2. 化简：7 个标称值 → 3 个待测量

### 2.1 电平移位零点直接约掉

把 $V_o$ 的表达式代入端点差：

$$
V_{o1}-V_{o2}
=\frac{(1.55-c_1\frac{3.3}{65536})-(1.55-c_2\frac{3.3}{65536})}{0.33}
=\frac{3.3\,(c_2-c_1)}{65536\times0.33}
$$

**$1.55\,\text{V}$ 消失了。** 它只影响阈值码与拉回目标，**不进入测量公式** ——
所以它根本不需要标定。（这是第一个"少一个待测量"。）

### 2.2 电容与电平移位增益分不开、也不用分

定义

$$
\boxed{\;q\;\equiv\;\frac{C\cdot V_{\text{ref,adc}}}{65536\cdot G}\;}
\qquad\text{[C/码]}
$$

其中 $G=0.33$ 是电平移位增益，$V_{\text{ref,adc}}=3.3\,\text{V}$ 是 ADS8866 的基准。
标称值 $q_0=1.5259\times10^{-14}\ \text{C/码}$。

**注意 $C$ 在整个公式里只出现在 $q$ 里，别处一次都不出现** ——
所以"电容的具体值"既测不出（与增益解耦不了）也不必测，**测它们的乘积即可**。
（第二个"少一个待测量"。）

同理 $I_\pm = V_{\text{ref}}/R$，**电压比电阻更准，但两者的乘积才是要测的量**。

### 2.3 化简后的测量式

$$
\boxed{\;
I=\underbrace{q\cdot\frac{c_2-c_1}{(m+n)\,T}}_{\text{端点项}}
 \;-\;\underbrace{\frac{m\,I_{+}+n\,I_{-}}{m+n}}_{\text{计数项}}
\;}
$$

**待测常数只剩三个：$q$（或等价地 $M$）、$I_{+}$、$I_{-}$。**
（$T$ 由 HSE 晶振决定，实测偏差 1.4 ppm，视为已知。）

---

## 3. 第一个岔路：$q$ 不能用"参考断开"来测

最直白的 $q$ 测法：**参考断开**、灌入已知电流 $I$、积分已知时间 $T_{\text{int}}$、
读码差 $\Delta c$，则

$$
q=\frac{I\cdot T_{\text{int}}}{\Delta c}
$$

两点一除，无拟合。**但"参考断开"是个陷阱。**

ADG1219 是**单刀双掷**：`EN=0` 时两路都断，100 MΩ 那一端是 **Hi-Z、并非 0 V**。
该浮空节点只靠寄生电容 $C_p$ 上的残余电荷经 100 MΩ 泄放到虚地：

$$
i(t)=\frac{V_n}{R}e^{-t/\tau},\qquad \tau=R\,C_p,\qquad
Q_{\text{注入}}=C_p V_n
$$

取 $C_p=10\ \text{pF}$（普通 PCB 节点量级）：$Q_{\text{注入}}=50\ \text{pC}$，
折合码差 $50\,\text{pC}/q_0\approx3277$ 码；而信号（50 nA 积分 8 ms）约
$26212$ 码 —— **误差 12.5%**。

**结论：$q$ 必须换一种测法。** 本文第 5 节的杠杆分析会给出更好的方案。

---

## 4. 可识别性分析

把式(6) 的三个常数当未知数，写成线性模型。令

$$
a_1=\frac{\Delta V_{\text{raw}}}{(m+n)T},\qquad
a_2=\frac{m}{m+n},\qquad
a_3=\frac{n}{m+n}
$$

（$\Delta V_{\text{raw}}$ 是由原始码直接折算的 ADC 域电压差，见 6.1 节）

则

$$
I_x=M\,a_1-I_{+}a_2-I_{-}a_3
$$

### 4.1 一个恒等式带来的共线

$$
a_2+a_3\equiv1
$$

**只要把 $a_2$、$a_3$ 各作一列去做回归，两列就是共线的**，各自的标准误会
被放大十几倍。代入 $a_3=1-a_2$ 可得**等价的重参数化**：

$$
I_x=M\,a_1+\underbrace{(-I_{-})}_{b_0}
+\underbrace{(I_{-}-I_{+})}_{b_2}\,a_2
$$

三列 $(a_1,\ 1,\ a_2)$ **条件数良好**。反解：

$$
I_{-}=-b_0,\qquad I_{+}=I_{-}-b_2
$$

**所以 $I_{+}$、$I_{-}$ 都是可识别的** —— 只是不能按它们各自一列去拟合。

### 4.2 实验数据验证

用合成数据（$C_p$ 无关，纯代数）实测：$(a_1,1,a_2)$ 的条件数为 **20**，
$a_1$ 与 $a_2$ 的相关系数只有 **0.019** —— **共线在设计上被绕开了**。

---

## 5. 核心：两个杠杆——一个受控，一个不受控

**这是本方案最关键的一节。** 三个常数可以放进同一个最小二乘，但它们在数据里的
"信息量"完全不同 —— 而且**其中一个的信息量依赖于一个未经验证的假设**。

### 5.1 杠杆的定义

定义参数 $p$ 的**杠杆**为其对应项在数据集上的**跨度**：

$$
L_{\text{端点}}=|M|\cdot\big[\max(a_1)-\min(a_1)\big],\qquad
L_{\text{计数}}=|b_2|\cdot\big[\max(a_2)-\min(a_2)\big]
$$

参数标准误近似满足 $\sigma_p\propto\sigma_{\text{噪声}}/(L_p\sqrt N)$ ——
**杠杆越小，这个参数越定不准。**

### 5.2 一个受控，一个不受控

| 项 | 杠杆由什么决定 | 能不能在设计阶段保证 |
|---|---|---|
| 计数项 $(I_{-}-I_{+})a_2$ | **占空比的跨度** | ✅ **能** —— 只要已知电流覆盖足够宽的范围，占空比必然大范围变化 |
| 端点项 $M\,a_1$ | **端点码差的跨度** | ❌ **不能** —— 见 5.3 |

计数项杠杆是**实验设计的直接后果**：要求"已知电流跨量程、正负都有"，
占空比 $a_2=m/(m+n)$ 就必然从 0.2 扫到 0.8，杠杆稳定在 **60 nA** 量级。

$$
L_{\text{计数}}=(I_{-}-I_{+})\cdot\Delta a_2\approx100.5\ \text{nA}\times0.6=\mathbf{60\ nA}
$$

**这一项不依赖任何假设。**

### 5.3 端点差为什么不受控

端点码差

$$
\Delta c=c_2-c_1
$$

- **起点** $c_1$ = 拉回相最后一拍，落在零点附近，过冲约一拍的路程 ≈ 525 码
  —— **几乎不随被测电流变化**
- **终点** $c_2$ = 窗口结束时锯齿所处的相位

关键在于：**这个相位是确定性的，不是随机的**。窗口长度固定为 6250 拍，
锯齿周期由被测电流决定，于是

$$
\text{终点相位}=(6250\bmod \text{周期}(I_x))
$$

**同一个被测电流重复测，相位每次都一样** —— 重复测量只能压低 $\Delta c$ 的**噪声**，
不能增加它的**跨度**。跨度只能在**换不同的 $I_x$** 时才产生，而变多少取决于
"周期随 $I_x$ 怎么变"与"模 6250"的关系 —— **没有任何保证**。

**极端情况下**：若相位在各次测量间几乎不变，$\Delta c$ 近乎恒定，$a_1$ 与常数项
共线，**$M$ 完全不可识别**（自测第 3 项就是这个退化情形，条件数飙到 $10^{17}$）。

### 5.4 结论：不要赌这个假设

| 量 | 杠杆受控？ | 用什么方法 |
|---|---|---|
| $I_{+},I_{-}$ | ✅ 受控（占空比） | **闭环最小二乘拟合**，精度由设计保证 |
| $q$ | ❌ **不受控** | **专门的"灌已知电流"开环测量** |

**开环测量**：固定参考极性（**不进 `EN=0`**，见第 3 节）、灌入已知电流、
让 $\Delta c$ 跑满整条斜坡：

$$
q=\frac{I\cdot T_{\text{int}}}{\Delta c}
$$

- 开环时 $\Delta c$ 由电流与积分时长决定，**可以主动设计**（如 50 nA × 8 ms
  ≈ 26000 码），不依赖锯齿相位
- 重复 $N$ 次取均值，再降 $\sqrt N$
- **且必须避开 `EN=0`** —— 那条路的 Hi-Z 暂态会给 $q$ 带来 12.5% 的误差

> **所以"不同量用不同方法"的准确表述是：算法相同（都是最小二乘），
> 但实验条件不同 —— $I_\pm$ 可以从闭环数据里稳定拿到；$q$ 的杠杆依赖一个
> 无法在设计阶段保证的假设，因此必须用开环测量单独测。**

### 5.5 方法学教训：不要靠猜，要靠量（本文栽了两次）

本文的杠杆分析先后取过两个端点码差量级，**两个都没有依据**：

| 取值 | 得到的杠杆比 | 得到的结论 |
|---|---|---|
| $\pm2000$ 码 | 960 : 1 | $q$ 只能定到 0.45%，**必须另测** |
| $\pm28000$ 码 | 71 : 1 | $q$ 能定到 0.032%，**够用了** |

**两个结论完全相反，而两次都是猜的。**

**正确的做法是量出来。** 第一次实测之后，直接看 `make_fit_csv.py` 打印的表里
`c2-c1` 那一列的跨度：

- 跨度铺满大半个摆幅 → 闭环拟合的 $M$ 可用
- 跨度只有几万分之一 → 用开环测量

而 `fit_constants.m` 会把这个杠杆按实测数据算出来并打印 —— **不需要预先假设**。

> **教训：凡是决定结论正负的量，必须先测，不能先猜。**
> 自测脚本里现在也直接标注了这个推导（见 `scripts/analysis/test_fit_constants.m`）。

---

## 6. 程序设计的考量

### 6.1 码差必须在整数域相减

端点电压差若写成

$$
\frac{V_{\text{ref}}c_2}{65536}-\frac{V_{\text{ref}}c_1}{65536}
$$

在 $\Delta c$ 很小时会发生**灾难性抵消**：两个接近的大数相减，有效位大量丢失。

**正确做法是先做整数减法**：

$$
\Delta c=c_2-c_1\quad(\text{精确整数}),\qquad
\Delta V_{\text{raw}}=V_{\text{ref}}\cdot\frac{\Delta c}{65536}
$$

原始码 $\le 65535\ll 2^{53}$，双精度表示整数是**精确**的，所以这步没有舍入。

### 6.2 用 QR，不用正规方程

最小二乘的解若通过正规方程

$$
\hat x=(A^{\mathsf T}A)^{-1}A^{\mathsf T}y
$$

求得，**条件数会被平方** —— 原本 $10^3$ 的病态会变成 $10^6$，有效数字直接损失一半。

**正确做法是用 QR 分解**（MATLAB 对超定系统 `A\b` 即走 QR）。
正规方程只在**估计参数方差**时使用（那里条件数只有几十，安全）。

### 6.3 重参数化以避免共线

见 4.1 节。直接拟合 $(a_1,a_2,a_3)$ 三列会因 $a_2+a_3\equiv1$ 而共线；
改用 $(a_1,1,a_2)$ 后条件数降到 20。

### 6.4 $\texttt{vpa}$ 的定位：复核算术，不提高数据精度

输入是**测量值**，本身只有几位有效数字 —— 用 50 位浮点去解**不会让结果更准**。

但 $\texttt{vpa}$ 有另一个用处：**独立复核双精度的算术有没有损失**。脚本用
三种方式各解一遍（QR、中心化 QR、$\texttt{vpa}$ 50 位正规方程）并比较：

- 三者一致到 $10^{-23}$（无噪声合成数据）→ 双精度没有损失
- 若不一致（如退化数据）→ **立即报警，结果作废**

### 6.5 报告标准误，而不只是点估计

**只给一个拟合值是不够的** —— 必须同时给出它准到什么程度。脚本用

$$
\operatorname{se}_j=\sqrt{\hat\sigma^2\left[(A^{\mathsf T}A)^{-1}\right]_{jj}},
\qquad \hat\sigma^2=\frac{\text{RSS}}{N-k}
$$

输出每个参数的标准误，并**自动计算并打印杠杆对比**（5.1 节），
主动告诉使用者"哪一个参数不该信"。

### 6.6 数据配对交给机器

拟合的因变量是**已知输入电流**，自变量来自**同一次测量**的 `RAW` 段。
手工把两者配对极其容易错位，而且**错得不明显**（拟合照样跑出数，只是结果是错的）。

因此设计成：采集时用 `--true=` 把真值写进数据文件，再由脚本自动汇总。
跳过原因（缺 `RAW` 段、缺真值、超时）逐条打印，**绝不静默丢数据**。

### 6.7 自测用合成数据

校准链路可以在**不接任何硬件**的情况下自测：给定一组"真常数"，用模型生成
合成数据，再跑拟合看能否还原。脚本的自测覆盖：

| 用例 | 期望 |
|---|---|
| 无噪声 | 精确还原（相对差 $10^{-14}$ 量级） |
| 加码噪声（68 码） | 误差与预测标准误同量级 |
| 退化数据（端点差恒定） | 条件数 $\to10^{17}$，**正确报警** |
| 不同量程覆盖 | 条件数稳定在 20 |

---

## 7. 交叉验证

拟合物量参数相较经验拟合（$I_{\text{cal}}=a\,I_{\text{raw}}+b$ 分段）的**根本优势**：
**每个参数都能独立验证**。

| 拟合量 | 应接近 | 独立来源 |
|---|---|---|
| $I_{-}$ | $-50.255\ \text{nA}$ | $V_{-}/R$（万用表量压降） |
| $I_{+}-I_{-}$ | $+100.487\ \text{nA}$ | $V_{+}/R_{+}-V_{-}/R_{-}$ |
| $M$ | $3.03\times10^{-10}$ | 即 $q\cdot65536/3.3$ |

**对不上就说明模型或数据有问题** —— 分段经验拟合做不到这一点（它拟合出来的是黑盒）。

---

## 8. 已知限制

1. **$R$ 的测量精度是弱环节。** 万用表在 100 MΩ 量程只有 ±1%，
   而 $I_\pm$ 的**共同尺度**误差是纯增益、**不对称**部分是纯偏移，两者都能被
   参数拟合吸收 —— 但**参考电流的温漂**会 1:1 进入读数，是不确定度预算里
   权重最大的一项。

2. **$q$ 的闭环拟合值（0.03%）已经够用**；只有当需要更高精度时才做开环测量。
   而**开环必须避开 `EN=0`**（第 3 节）：把 ADG **固定在一个极性**、以参考电流
   自身作为已知电流来自标。这需要一个"固定极性积分"的固件模式（**尚未实现**）。

3. **本文所有精度数字来自合成数据。** 实测的性能要在硬件上验证后才能定论。

---

## 附：可复现的工具链

| 文件 | 作用 |
|---|---|
| `scripts/smu/nanoammeter_capture.py` | 采集，`--true=<nA>` 记录已知真值 |
| `scripts/analysis/make_fit_csv.py` | 汇总 npz → CSV，自动配对并报告跳过原因 |
| `scripts/analysis/fit_constants.m` | 最小二乘拟合 + 标准误 + 杠杆诊断 + $\texttt{vpa}$ 复核 |
| `scripts/analysis/test_fit_constants.m` | 合成数据自测（无需硬件） |
| `scripts/analysis/test_make_fit_csv.py` | CSV 工具回归测试 |
| `docs/拟合操作指南.md` | 面向初学者的逐步操作说明 |

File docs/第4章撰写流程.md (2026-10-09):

# 第 4 章「性能评价与校准」—— 撰写与执行流程（最终版）

> 本流程把原第 4 章草稿与**物理常数标定方案**合并后的结果。相对原稿的主要改动列在
> 第 6 节，便于对照。

---

## 0 两条前置 —— 卡着后面好几步

| # | 做什么 | 为什么卡 |
|---|---|---|
| **P1** | **量出复位相寄生放电的时间常数 τ** | 所有"`EN=0` 当零参考"的测量（小电流模式、底噪、零位检查）都受它污染。**τ 不出来，4.3 和 pA 段全部无依据** |
| **P2** | **实现"固定极性积分"固件模式** | ① `q` 的开环标定 ② P1 那个 τ 的量测 —— **同一个模式一次解决两件事** |

**P2 → P1 → 后面全部。** 这两条不做，第 4 章只能写到一半。

---

## 1 章节结构与每节的数据来源

| 节 | 内容 | 数据从哪来 | 工作量 |
|---|---|---|---|
| 4.1 | 性能指标定义 | 纯定义 | 无 |
| 4.2 | **测量链关键参数表征** | `V₊`、`V₋`、`R` **三个数** | 已基本完成 |
| 4.3 | 未校准性能表征 | 零输入重复测量 + 重复性 | 中，**依赖 P1** |
| 4.4 | 校准点数据采集 | **核心测量战役** | 大 |
| 4.5 | 标定模型 | 4.4 的数据 → 拟合 | 小（工具已就绪） |
| 4.6 | 独立验证 | 未参与拟合的新点 | 中 |
| 4.7 | 不确定度评定 | 前几节的输出 | 小 |
| 4.8 | 性能指标汇总 | 汇总，**不做新实验** | 无 |
| 4.9 | 检测下限 | **从 4.4/4.6 的数据里找** | 小 |
| 4.10 | 应用验证（光电管） | 新测量 | 中 |
| 4.11 | 小结 | — | 无 |

---

## 2 执行顺序（每次上板做什么）

```
上板 ①  实现"固定极性积分"模式 → 上板 → 量 τ
        └ 决定 pA 段与零位测量能不能用

上板 ②  4.2 三个数（万用表，五分钟）
        4.4 校准点数据 ★核心★
        └ nA 三段、正负，每点 3 次，**每个点还要记 RAW 段四个数**

上板 ③  q 的开环标定（用 P2 那个模式）
        └ 与闭环拟合值交叉对照

上板 ④  4.6 独立验证点（未参与拟合的点）

上板 ⑤  4.3 零输入（τ 解决之后）+ 4.9 检测下限补点

上板 ⑥  4.10 光电管应用
```

---

## 3 每张表怎么填

### 3.1 4.2 三个数（不是三张表）

| 量 | 值 | 用途 |
|---|---|---|
| `V₊` | 4.99703 V | **和拟合出的 `I₊` 对照** |
| `V₋` | −4.99938 V | **和拟合出的 `I₋` 对照** |
| `R` | 99.48 MΩ | 同上 |

> **这三个数不进不确定度预算** —— 拟合之后它们的误差已被吸收进 `I₊`/`I₋`。
> 它们唯一的用途是**交叉验证**：拟合值对不上 `V/R` 就说明模型或数据有问题。
>
> **原表 4-4（3.3 V ADC 基准）可以整节删除** —— 它只进 `q`，而 `q` 是实测的。

### 3.2 4.4 校准点 —— **每个点必须多记四个数**

这是新方案相对原稿**唯一增加的记录负担**：

| 记录项 | 从哪读 |
|---|---|
| `I_std` 标准值 | 2636B 回读 |
| `I_raw` 电路板读数 | 结果行的 `I=`（内置）或 `X=`（外部 ADS8866） |
| **`m`、`n`** | 结果行 `RAW` 段的 `m=` / `n=` |
| **`c₁`、`c₂`** | 同一个 `RAW` 段的 `INT1`/`INT2`（或 `EXT1`/`EXT2`） |

**采集时带上 `--true=` 自动记账，事后由脚本配对：**

```bash
python scripts/smu/nanoammeter_capture.py COM7 --no-noise --true=25.0
python scripts/analysis/make_fit_csv.py -d . -o fit_data.csv      # 自动配对，不要手工抄
```

> ⚠️ **已知电流必须 ≥ 1 nA** —— 式(6) 是模式一的公式；低于 1 nA 固件自动切小电流
> 模式，**那条路不出 `RAW` 段**，采了也用不上。

### 3.3 4.5 表 4-15 —— **整张换掉**

原来的"三段各一套 `a`/`b`"改成：

| 常数 | 拟合值 | 标准误 | 独立对照 | 来源 |
|---|---|---|---|---|
| `q` | — | ± | （标称 1.5259e-14 C/码） | **开环标定** |
| `I₊` | — | ± | ≈ +50.232 nA（`V₊/R`） | 闭环最小二乘 |
| `I₋` | — | ± | ≈ −50.255 nA（`V₋/R`） | 闭环最小二乘 |

```bash
bash scripts/analysis/matlab_utf8.sh "cd('scripts/analysis'); fit_constants('../../fit_data.csv')"
```

拟合程序会直接输出：三个值 + 各自标准误 + 与独立测量的对照 + **杠杆对比**
（判断哪个常数可信度低）。结尾还会给一行**可直接粘给固件的 `Q` 指令**。

**分段依据、区间边界、各段 R² —— 那套论证全部不用写了。**

### 3.4 4.9 检测下限 —— 从数据里找，不单独跑

在 4.4 / 4.6 的数据里找 **|δ| 越过 5%** 的位置，在其两侧各补 2~3 个点卡边界即可。
**不需要"逐级减小"单独做一轮。**

---

## 4 不确定度预算（改过的版本）

| 分量 | 类型 | 量级 | 来源 |
|---|---|---|---|
| 重复性 | **A** | 每点 3 次的 `s/√3` | 统计 |
| **2636B 标准值** | **B** | **±0.10%**（100 nA 档，按证书核对） | 仪器证书 |
| 被测板读数分辨力 | B | `q/√12` | 设计值 |
| **拟合常数不确定度** | **A** | `I±` ≈0.0004%、`q` ≈0.03% | **拟合直接给出** |
| 温漂 | B（若已量化） | — | 独立实验 |

**没有 `V_ref`、没有 `R`。** 它们已被吸收进 `I±` 的拟合值。

> **值得写进正文的一句**：2636B 的 ±0.10% 比拟合不确定度（0.0004%）大 250 倍 ——
> **本系统的准确度由校准标准决定，不由仪器本身决定。**

合成标准不确定度按方和根合成，取 `k=2` 报扩展不确定度。

---

## 5 报告里要保留的三条"A 类"优势

新方案相对经验拟合（分段 `a`/`b`）的三点，值得在 4.5 / 4.6 里点明：

1. **参数可独立验证** —— 每个拟合常数都能和 `V/R` 对照（黑盒拟合做不到）
2. **交叉校验** —— `q` 的开环标定值与闭环拟合值可互相印证
3. **标准误随结果一起给出** —— 标定值的可信度是**量化**的，不是"看起来不错"

---

## 6 相对原稿的改动清单

| 原稿 | 新流程 |
|---|---|
| 4.2 三张参数测定表 | **缩成三个数**，用途改为交叉验证 |
| 4.2.2（3.3 V ADC 基准） | **删除** —— 只进 `q`，而 `q` 实测 |
| 4.4.2 按量级分段原则 | **删除** —— 物理模型全量程通用，不需分段 |
| 4.5 表 4-15 分段系数 | **换成物理常数表**（3 个参数 + 标准误 + 独立对照） |
| 4.4 / 4.6 每点记录 | **增加 `m`/`n`/`c₁`/`c₂` 四项** |
| 4.7 不确定度预算 | **加两项 A 类**（拟合标准误），**去掉 `V_ref`/`R`** |
| 4.9 检测下限单独跑 | **从已有数据推**，补 2~3 点 |
| 响应时间（表 4-19） | **降级** —— 本仪器按 1 s 窗口工作，响应时间即窗口时长，一句话说明即可；测微弱直流时该指标不重要 |
| 细步进输入验证 | **降级** —— 重复测量的标准差才是分辨率的直接定义，有余力再做 |
| — | **新增 P1/P2 两条前置** |

---

## 7 待实现清单（代码侧）

| 项 | 卡住哪一步 |
|---|---|
| **"固定极性积分"固件模式** | P1（量 τ）、4.5 的 `q` 开环标定 |
| τ 的测量流程 | 4.3（零位/本底噪声）、pA 段全部 |

**其他工具已就绪**：采集脚本（`--true=` 记账）、CSV 汇总、MATLAB 拟合、自测。

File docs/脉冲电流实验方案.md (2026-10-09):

# 脉冲电流测量实验方案

> **目的**：为报告里的"**适合测量微弱脉冲信号**"这句话提供实验证据。
> **状态**：方案已定，**等 2636B 的网线到位后执行**。
> **前置**：装置固件用 `firmware-v1`（含 `M` 指令那版），已烧录。

---

## 1 要证明什么 —— 三条证据链

一句性能声明，评审会问证据。至少要这三条，缺一条那句话就是空的：

| # | 证据 | 做法 | 说明什么 |
|---|---|---|---|
| **E1** | **读数 vs 占空比 线性** | 峰值固定，`duty` 从 50% 扫到 1% | 平均特性正确 |
| **E2** | **读数 vs 峰值 线性** | 占空比固定，峰值扫一遍 | 大信号不被压缩 |
| **E3** | **脉冲 ≡ 等效直流** | 例如 `40nA × 25%` 对 `10nA 直流` | **最关键**：脉冲本身不引入误差 |

**E3 是核心。** 同一个 10 nA，用直流给和用脉冲给，读数应当一致到仪器的准确度
（未校准 ~1.3%）以内。这条一旦成立，"脉冲不影响准确度"就证完了。

E1/E2 是补充，用来证明"不是碰巧在一个点上对"。

---

## 2 原理与可测边界

### 2.1 为什么这是**结构性优势**，不是勉强能用

电荷平衡本质上是**电荷积分器 + delta-sigma 调制器**：

```
它输出的不是"某一时刻的电流"，而是"窗口内累计的电荷 ÷ 窗口时长"
                                    = 窗口内的平均电流
```

**对脉冲信号不需要任何额外处理** —— 平均就是它的天然输出。
用 ADC 直接采样的方案反而要面对混叠、峰值检波、同步采样这一堆问题。

### 2.2 四条边界（定量）

| 约束 | 式子 | 来源 |
|---|---|---|
| 单脉冲电荷不撞轨 | `I_peak × t_on < 430 pC` | 100 pF × 4.3 V 摆幅 |
| 平均电流在量程内 | `I_peak × duty < 45 nA` | 参考电流 ±50 nA |
| 周期 ≪ 窗口 | `T_period ≪ 1 s` | 平均要有意义 |
| 上行带宽 | 极窄脉冲（<1 µs）会被平滑 | 运放 + 100 pF |

由前两条：

```
I_peak < min( 430 pC / t_on ,  45 nA / duty )
```

| 脉冲 | 峰值上限 | 谁卡的 |
|---|---|---|
| 100 µs / 10 ms（1%） | 4.3 µA | 电荷 |
| 100 µs / 1 ms（10%） | 430 nA | 平均 |
| 1 ms / 10 ms（10%） | 430 nA | 电荷 |
| 1 ms / 100 ms（1%） | 430 nA | 电荷 |
| 10 ms / 100 ms（10%） | 45 nA | 回到直流上限，**无优势** |

### 2.3 占空比能测多准 —— 决定周期下限

2636B 的脉宽指标：**准确度 ±5 µs，抖动 2 µs**（1 µs 编程分辨率）。

```
占空比误差 = 脉宽误差 / 周期     (不是 / t_on!)
  T =   1 ms  ->  0.5%     ✗ 太差
  T =  10 ms  ->  0.05%    ✓
  T = 100 ms  ->  0.005%   ✓
```

**所以周期取 ≥ 10 ms。** 抖动那一项是随机的，100 个脉冲平均后降 √100 = 10 倍。

---

## 3 实验点表

**点表的唯一来源是 `scripts/smu/sweep_pulse.py` 里的 `POINTS`（20 组）+ `DC_POINTS`（8 个直流对照）。**
运行 `python scripts/smu/sweep_pulse.py --list` 打印当前点表、逐点的约束余量和时间估算。
本节只记**为什么这么设计**，具体数值不再复制一份（复制必失同步）。

### 3.1 约束（决定点能放在哪里）

```
① 电荷回收:  ton 期间灌入的电荷必须在 toff 期间被参考抽走, 参考只有 50 nA
             I_peak × t_on ≤ I_ref × t_off    ⟹    I_avg ≤ 50 nA × (1 − D)
② 量程:      I_avg ≤ 45 nA
③ 纹波撞轨:  I_avg × T ≤ 摆幅电荷 100 pF × 8.6 V = 860 pC
```

**合并：`I_avg ≤ min( 45 nA , 50 nA×(1−D) , 860 pC/T )`**

在 T = 10 ms 下 ③ 给出 86 nA，**永远比 ①② 松**——只在 T ≥ 20 ms 时才起作用
（D3 组就是贴着它的点）。所以实际是：

| 占空比 | 上限 | 谁卡 |
|---|---|---|
| 50% | 25 nA | 电荷回收 |
| 25% | 37.5 nA | 电荷回收 |
| 20% | 40 nA | 电荷回收 |
| 10% | 45 nA | 两条相等 |
| ≤ 10% | 45 nA | 量程 |

> **占空比 > 10% 时"电荷回收"卡死；≤ 10% 时"量程"卡死。**
> （设计点表时原方案写"200 nA 峰值超量程 4.4 倍"是**可行的**，但必须满足上面这条，
> 不是只看 `I_peak × t_on` 那一条。）

### 3.2 五组的分工

| 组 | 扫描量 | 固定量 | 证明什么 |
|---|---|---|---|
| **A** | 占空比 50→2.5% | 峰值 40 nA | `I_avg = I_peak × D` |
| **B** | 峰值 1→400 nA | 占空比 10% | 幅度线性；**超量程主线** |
| **C** | 峰值 5→200 nA | 占空比 20% | 第二条占空比上的线性；**卡约束角点** |
| **D** | 周期 10→40 ms | 峰值 40 nA / 25% | 周期无关性 + 折叠周期数 |
| **E** | — | — | **极限状态（2 组）** |

### 3.3 极限状态（E 组）

- **E1 大峰值**：峰值 **1 µA** / 0.4 ms / 10 ms → `I_avg` = 40 nA。
  峰值是 ±45 nA 直流量程的 **22 倍**，但平均仍在量程内，**应当通过**。
  **这是报告里最漂亮的一行。**
- **E2 越界**：峰值 120 nA / 5 ms / 10 ms → `I_avg` = 60 nA，**超上限 140%**，
  **应当失败**。用来确定失效模式长什么样（`m` 或 `n` 归零、`PRE` 计数增加）。
  报告里可以不写，但做实验时值得知道边界在哪。

### 3.4 直流对照与交织顺序

8 个直流对照点 `0.1 0.5 1 2 4 10 20 40 nA` 覆盖 20 组脉冲的全部 `I_avg` 取值。
多数直流点配到 2 组以上脉冲（10 nA 配到 5 组）。所以 E3 不是"两条曲线贴一起"，
而是**同一个平均值下多种完全不同的波形给出同一个读数**。

采集**按 `I_avg` 分组交织**：同一平均电流下的脉冲点跑完，紧跟该点的直流对照。
不逐点配直流是为了省时间；不"全部脉冲跑完再跑全部直流"是为了**抑制源表漂移**
（相隔三小时的两次读数比较不可信）。

### 3.5 一个已知限制

`B1`/`B2`（`I_avg` < 1 nA）会落进 10 s 窗口（`measurement_state.c:115` 自动切换）。
固件抽点后 1.6 ms/点，而 `t_on` = 1 ms < 1.6 ms → **平台在存储波形里不存在**。
平均值照样准（那是 E1/E3 要的），但**这两点不能做波形反演**。

---

## 4 2636B 脉冲配置

### 4.1 TSP 脚本（**2026-09-16 已跑通**）

> 手册出处：2600BS-901-01 **Rev. C**（2016），本地 `D:\451374.pdf`。
> 网上最新是 Rev. F（2021），差 5 年，对不上时优先怀疑版本。

2600B 系列用 `ConfigPulseIMeasureVSweepLin()` 生成脉冲串 —— 把起止电流设成
**同一个值**就得到等幅脉冲串。

官方签名（手册 7-38，**5 个重载、10~14 个参数**，后 4 个有默认值）：

    f, msg = ConfigPulseIMeasureVSweepLin(smu, bias, start, stop, limit,
                 ton, toff, points, buffer, tag,
                 sync_in, sync_out, sync_in_timeout, sync_in_abort)

**`toff` 是脉冲之间的间隔，周期 = ton + toff**，没有 pulsePeriod 参数；
测量在 **`ton` 结束**时做。

> ⚠️ **配置函数只做可行性校验，不碰触发模型。**
> 手册 7-39 原文："This function **does not cause** the specified smu to output
> a pulse train. It does check to see if all the pulse dimensions can be achieved,
> and if they can, assigns the indicated tag or index to the pulse train."
>
> 所以**配置返回 `true` 不等于能跑**；而且此时 `trigger.source.action` 仍是
> 0（未使能）—— **这是正常的，不是故障。** 本节原先把这条当成"配置没生效"
> 的证据，是**误判**，为此白查了一轮。

> ⚠️ **签名那条老结论仍然成立**：原来写的 8 参数版本
> `(smua, peak, peak, 1000, ton, toff, buffer, 1)` **整体串位两位**，
> 而 TSP 自己做类型转换**不报错**，静默地什么都没配上。现行代码参数顺序已对。

#### 三条前置条件（`InitiatePulseTest` 会当场拒绝）

手册 7-113 列出，2026-09-16 单因素拆分实测确认，**下面是仪器自己返回的原文**：

| 前置条件 | 违反时的返回 msg |
|---|---|
| Source **autorange** 关 | `Source autorange must be disabled` |
| Measure **autorange** 关 | （同上，两路一起判） |
| Measure **NPLC < ton** | `Measurement aperture greater than pulse width` |
| Measure **autozero** OFF/ONCE | `Measure autozero must be off` |
| **Output on** + 缓冲 appendmode | （见下） |

**三处都是必需的（联合条件）**，不是"改哪一处都行" —— 单改任意一处、或任意两处
的组合，实测全部失败。校验按固定顺序做，每次只报第一条违规。

> ⚠️ **`autorangei = OFF` 只管电流那一路。** 电压那路（`autorangev`）是独立的，
> 要靠 `smua.source.rangev = 5` 关掉（设档位隐含关掉该功能的自动量程）。
> 漏了这一句仪器照样返回 `Source autorange must be disabled`，
> **而 `rangei` 读回来是对的，极易看漏** —— 2026-09-16 就栽在这。

> ⚠️ **失败原因只在 `InitiatePulseTest` 的返回值里，错误队列始终 0 条。**
> 必须 `print(InitiatePulseTest(1))` 读回 `f, msg`。用 `smu_write` 发就等于把
> 前置条件违规**全部变成"缓冲 0 点"的静默失败**，和"配置没生效"长得一模一样。
> 代码见 `scripts/smu/sweep_pulse.py` 的 `pulse_initiate()`。

```lua
-- 例：40 nA 峰值, 5 ms on / 5 ms off, 20 个脉冲
smua.nvbuffer1.clear()
smua.nvbuffer1.appendmode = 1      -- 不开厂脚本会拒绝 (>1 个脉冲时):
                                   --   false  Buffer must have appendmode activated...
smua.source.rangev = 5             -- 关源**电压** autorange (见上)
smua.source.rangei = 100e-9        -- **固定档, 必须覆盖峰值**
smua.measure.rangei = 100e-9
smua.measure.nplc = 0.01           -- **必须 < ton** (ton=5ms -> 孔径 0.2ms)
smua.measure.autozero = 1          -- AUTOZERO_ONCE。**用数值** —— 常量名
                                   -- 在该固件上报 -104 (见 cal_sweep.SMU_AUTOZERO)
smua.source.output = smua.OUTPUT_ON   -- 配置**前**就开输出

ConfigPulseIMeasureVSweepLin(
    smua,
    0,                 -- bias   脉冲**之间**的电平 —— **必须是 0**
    40e-9, 40e-9,      -- start, stop  取相同值 => 等幅脉冲串
    5,                 -- limit  顺从电压 (V)
    5e-3,              -- ton    脉宽 (s)
    5e-3,              -- toff   脉冲间隔 (s)
    20,                -- points = 脉冲个数
    smua.nvbuffer1,    -- 测量缓冲 (nil = 不测)
    1)                 -- tag    脉冲串编号, 给 InitiatePulseTest 用
print(InitiatePulseTest(1))            -- **必须读返回值**, 如 "true  Pulse completed"
```

#### 两个会**静默**毁掉实验的坑

> ⚠️ **① `bias` 必须是 0，传峰值等于没在做脉冲。**
> 本节原来写的是 `40e-9, -- bias 脉冲之间的电平` —— 把 40 nA 当成"脉冲之间的
> 电平"了，**那是错的**。手册两处例子都写死 0：7-40 的 SweepLin 例
> `ConfigPulseIMeasureVSweepLin(smua, 0, 0.01, 0.05, ...)` 配文
> "**return to a 0 mA bias level between pulses**"；7-37 的 IMeasureV 例
> `ConfigPulseIMeasureV(smua, 0, 5, 10, ...)` 配文 "return to **0 A** after 1 ms.
> The pulse will remain at **0 A** for 80 ms"。
>
> `bias = start = stop = 峰值` 时**波形自始至终不变，输出的是恒定直流而不是
> 脉冲串** —— 而仪器**不报错、缓冲照样填满 N 点**。每个"脉冲点"都会退化成
> "峰值直流点"，E1/E3 全部失真且查不出来。

> ⚠️ **② `InitiatePulseTest` 是阻塞的，会一直等到整串跑完。**
> 实测：返回 `true | Pulse completed` 的同时 `nvbuffer1.n` 已经满了。两个后果：
>
> - **脉冲个数不能随手给大数。** 给 100000 个（周期 10 ms）会把仪器占住
>   **1000 秒**，期间**所有**查询都超时，看着像死机（2026-09-16 真撞过，
>   最后靠等它跑完才恢复）。个数由 `scripts/smu/sweep_pulse.py` 的 `pulse_count()`
>   按**装置测量窗口**算，不再是固定值。
> - **装置测量必须放到另一个线程。** 主线程会一直卡在 `pulse_start()` 里，
>   同线程顺序执行的话，等它返回时脉冲早停了，装置测到 0。
>   见 `sweep_pulse.py` 的 `_measure_loop()` + `run_point()`。

> ⚠️ **附带一条**：`smua.reset()` **管不着 `trigger.timer`**（系统级对象，
> 手册列的影响项是 "Instrument reset" 而非 SMU reset）。实测 `smua.reset()`
> 前后 `trigger.timer[1].delay/count` 纹丝不动。低层 TSP 路线（§4.3）配置前
> 必须 `trigger.timer[1].reset()`。

### 4.2 注意事项

- **测量时刻**：2600B 在 `ton` **末尾**测量。所以它的回读值是**峰值**，不是平均。
  **平均要自己算**：`I_avg = I_peak × t_on / T`。
- **不要在脉冲模式下读 `smua.measure.i()` 当平均值** —— 那是峰值。
- **顺从电压**：**5 V**，不是 20 V。判据是"让输入级的钳位二极管永不通"，
  推导见 `docs/2636B源表接入.md` 第四节 —— 这不是余量问题，是 ADA4530-1 的
  损坏边界问题。
- **脉冲个数**：由 `scripts/smu/sweep_pulse.py` 的 `pulse_count()` 按**装置测量窗口**
  算（窗口 1 s / 10 s，见 §5.1），并留 (n+2) 个窗口 + 10% 余量。
  **不要再手填大数** —— `InitiatePulseTest` 阻塞，个数直接等于仪器被占住的时长。

### 4.3 备选（**已不需要 —— 脉冲编程 2026-09-16 已跑通**，此节仅作记录）

> 保留本节是因为下面"PC 直接翻转不行"那条实测结论仍有参考价值，
> 而且低层 TSP 路线（`scripts/smu/pulse_real.py --gen instr`）的定位变了：
> 它原本是"厂脚本调不通时退而求其次"，现在**不是必需品**，优先级可放低。

用 2636B 的**直流输出 + 外部斩波**（MOSFET 或干簧继电器）。缺点是斩波器的
导通电阻和电荷注入会引入新误差 —— **优先级低，只在脉冲模式实在调不通时用**。

> **2026-09-16 试过一条更省事的路，但它不行，记在这里免得有人重走**：
> **PC 直接翻转 `smua.source.output`**。时间基准是 PC，而每次翻转要走
> `write` + 查错误队列**两个 LAN 往返**，实测单次约 **150 ms** ——
> **完全盖过 ton/toff**：设定 200 ms 周期，实测 **547 ms**；占空比设定 50%
> 实测 54%。**只能做定性验证，做不了 "周期由仪器定" 的定量实验**，
> 且每周期只能几次电平跳变（做不了三角形那种几十级的）。
> 真要用 PC 这条路，必须像 `scripts/smu/pulse_real.py` 那样**记录实测翻转时刻**、
> 并且**按实测周期折叠**，否则相位是乱的。

---

## 5 采集流程

### 5.1 每个点

```bash
# --true= 填**平均值** (I_peak × duty), 不是峰值 —— 拟合/对比都按它
python scripts/smu/nanoammeter_capture.py COM6 --no-noise --true=<I_avg>
```

跑 3 次。**每次确认结果行的 `T=` 与预期的窗口一致**：

- `T=1000ms` = 1 s 窗口（`|I_avg|` ≥ 1 nA）
- `T=10000ms` = 10 s 窗口（`|I_avg|` < 1 nA，固件自动切换）

> **2026-09-13 起没有"小电流模式"了** —— 旧的 `SmallI_*` 代码已从固件删除。
> 现在**全量程是同一条逻辑**，只是 `|I|` < 1 nA 时窗口自动放长到 10 s
> （`measurement_state.c:115`）。`RAW` 段在两种窗口下**都会**输出
> （`main.c:119` 已修），所以"有没有 RAW"**不再是**判据。

### 5.2 对照组（直流点）

2636B 切回直流模式，按 `--true=` 填对应值。

### 5.3 每次记录

| 记录项 | 从哪来 |
|---|---|
| `I_peak` | 2636B 回读（脉冲末尾的瞬时值） |
| `t_on` / `T` | 程序设定值 |
| `I_avg` | 算出来的 |
| 装置读数 | 结果行的 `I=`（内置）/ `X=`（外部） |

> ⚠️ **别把 2636B 的回读峰值当成 `--true=`** —— 这是这个实验最容易犯的错。

---

## 6 数据分析

### 6.1 主图（报告用）

**横轴**：`I_avg` = `I_peak × duty`（计算值）
**纵轴**：装置读数

把脉冲点和直流点画在**同一张图**上：

- 脉冲点若与直流点**落在同一条直线上** → E3 成立
- 直线斜率即未校准增益（预期 ~1.01，与之前标定一致）
- 偏离直线的量即非线性

### 6.2 判据

| 判据 | 阈值 | 依据 |
|---|---|---|
| 脉冲读数 vs `I_avg` 的偏差 | **< 1.5%** | 未校准准确度 ~1.3% + 裕量 |
| 同一 `I_avg` 下脉冲与直流之差 | **< 0.5%** | E3 的直接检验 |
| 占空比扫描的线性度 | **< 0.5% FS** | 与直流线性度 0.0137% 对比 |

> 第二条是本方案的核心指标。如果它 < 0.5%，报告里就可以写
> "**脉冲调制不影响装置的准确度**"。

> ⚠️ **判据 2 的 0.5% 对最低两点（B1/B2，0.1 与 0.5 nA）太紧。**
> 这两点落在 10 s 窗口，读数噪声按 `σ_I × τ ≈ 0.8 pC` 折算，在 0.1 nA 上有
> 十几 pA 量级；但**脉冲点数也不多**（10 ms 周期、10 s 窗口 = 1000 个脉冲，
> 好在这比原来估计的多得多）。
> **仍然建议判据 2 按电流分档**：>1 nA 用 0.5%，<1 nA 用 2%；
> 或者对最低点单独报绝对偏差（pA）而不是相对偏差。

### 6.3 工具

**判据 1/2/3 已经实现在 `scripts/smu/sweep_pulse.py` 里**（采完自动打印，
并标出哪几行是"峰值超 ±45 nA 直流量程"的点）。
`scripts/analysis/analyze_pulse.py` 则读已存的 npz 离线重算/出图。

> 本节原来写"用 `scripts/analysis/fit_linearity.py` 打底，把 `I_true` 换成 `I_avg`"——
> 那已经过时：`analyze_pulse.py` 就是照这个思路写的，直接用它。

---

## 7 预期结果与风险

### 7.1 预期

- **A/B/C/D 组与 E1 应当给出正确的平均值**，偏差在 1.5% 内
  （主要是那个已知的 ~1.02% 增益误差）
- **B1/B2 落 10 s 窗口**，偏差应当更大一些（噪声按 `σ_I × τ ≈ 0.8 pC` 折算，
  在 0.1 nA 上相对误差被放大）
- **B6/C4/E1 贴着约束边界**（余量 11% / 0% / 11%），最可能先出现偏差
- **E2 应当失效**（`m` 或 `n` 归零 / `PRE` 增加），并在报告里作为"边界"说明

### 7.2 风险

| 风险 | 后果 | 缓解 |
|---|---|---|
| **2636B 脉冲模式调不通** | 实验做不了 | 按 §4.3 用直流 + 斩波；或先只做 E3（脉冲 vs 直流）这一个对比 |
| **脉冲"关断"时输出不是真 0 A** | 平均电流偏高 | **本装置输入是虚地，被运放钳住**，关断期间就是零电流 —— 风险低，但要实测确认 |
| **B1/B2 的平台被窗口抽点吃掉** | 平均值准但无法做波形反演 | 已在 §3.5 说明；想反演就改用 1 s 窗口（牺牲平均值精度） |
| **占空比算出误差** | `I_avg` 不准，判据失真 | 周期 ≥10 ms（§2.3）；每点记录 `I_peak`/`t_on`/`T` 原始值 |

---

## 8 报告里怎么写

做完之后，这一段可以直接用（把数字填上）：

> ### 4.x 脉冲信号的测量能力
>
> 本装置采用电荷平衡原理，**输出量本身就是积分窗口内的平均电流**，
> 因此对脉冲电流信号无需额外处理。为验证这一特性，以 2636B 源表输出
> 已知峰值与占空比的脉冲电流（周期 10 ms ~ 40 ms，占空比 2.5% ~ 50%，
> 峰值 1 nA ~ 1 µA），与相同平均值的直流信号对照测量，共 20 组脉冲 + 8 个直流点。
>
> 结果表明，在平均电流 0.1 nA ~ 40 nA 范围内，脉冲信号的读数与等效直流
> 信号的读数之差不超过 **○.○%**（表 4-x）；占空比在 2.5% ~ 50% 范围内变化时，
> 读数与计算平均值的偏差不超过 **○.○%**，无明显系统性趋势（图 4-x）。
>
> 值得注意的是，**峰值 1 µA 的脉冲信号（超出装置 ±45 nA 的直流量程
> 22 倍）**仍能被正确测量为 40 nA —— 这是平均型测量相对瞬时采样型测量的
> 固有优势。
>
> 因此，本装置适用于测量**微弱脉冲电流信号**，例如斩波光源下的光电流、
> 低占空比的脉冲激励响应等。适用的边界由三条约束共同决定
> （见 §3.1）：`I_avg ≤ min( 45 nA , 50 nA×(1−D) , 860 pC/T )`。

---

## 9 执行清单

> **前置条件已全部满足**（2026-09-16）：2636B 在 `192.168.0.2` 可连；
> 装置在 **COM6**（CH340）。文档早先写的 COM8/COM5 是旧的 —— **COM5 是 ST-Link
> 的 VCP，不是数据口**，照它连会连不上。

- [ ] 给装置断上电一次（实测第一次连不上时断电重上电就能解决）
- [ ] `python scripts/smu/sweep_pulse.py --list` 核对点表与约束余量
- [ ] **`--check`** 脉冲串自检：切模式→开输出→配置→启动→看缓冲。
      要求 `Initiate 返回: true` 且缓冲点数 = 脉冲个数
- [ ] **`--wavecheck`** 波形自检：直流基准 vs 50% 脉冲，要求比值 ≈ **0.5**。
      比值 ≈ 1.0 说明 `bias` 还是峰值（§4.1），**这时不能往下采集**
- [ ] 确认回读值出现在 `ton` 末尾（即峰值）
- [ ] 按 §3 的表逐点采集（脚本已按 `I_avg` 交织排列）
- [ ] 每次确认结果行的 `T=` 与预期窗口一致（1000ms / 10000ms）
- [ ] 直流对照点（8 个，脚本自动交织）
- [ ] 出主图（脉冲点 + 直流点同一张图）
- [ ] 算 §6.2 的三个判据
- [ ] 把 §8 那段填上数字，放进报告 4.x

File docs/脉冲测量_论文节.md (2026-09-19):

# 4.x 脉冲电流测量能力

> 论文用节。数据：`data/sweep_pulse_r1.csv`（A/P 组）、`data/sweep_pulse_r1_K.csv`（K 组），
> 32 个脉冲点 × 5 次重复，2026-09-16 采集。
> 装置状态：三常数 `q=15596 aC, I₊=49712 pA, I₋=−49739 pA`（`Q` 回读）；
> 分段校准为恒等（`a=1.0, b=0`，`C` 回读）；报数取 `CAL=` 通道。

## 4.x.1 实验方法

**测量原理。** 本仪器基于电荷平衡原理，其输出量本身就是积分窗口内的平均电流

$$I_{\text{out}}=\frac{1}{\tau}\int_{t-\tau}^{t} i(t)\,\mathrm{d}t$$

因此对脉冲电流**无需任何额外处理**——平均值即是它的天然输出。相较瞬时采样型仪器，
它不受峰值检波、频谱混叠与同步采样等问题的约束，这是原理层面的结构性优势。

**激励源。** 由 2636B 源表以 TSP 脉冲模式产生峰值为 $I_p$、导通时间 $t_{on}$、
周期 $T$ 的等幅脉冲串。仪器侧须满足三条前置条件：源与测量的自动量程均关闭、
测量积分时间小于 $t_{on}$、自动调零置于 ONCE；且**脉冲之间的基值电平必须为 0**。

**测试点设计。** 三组扫描，共 32 个脉冲点，另配 13 个直流对照点：

| 组 | 点数 | 扫描量 | 固定量 | 目的 |
|---|---|---|---|---|
| **A** | 12 | 占空比 50% → 2.5% | $I_p$ = 40 nA，$T$ = 10 ms | 验证 $I_{avg}=I_p t_{on}/T$ |
| **P** | 11 | 周期 50 → 1 ms | $I_p$ = 40 nA，$D$ = 25% | 逼近周期下限 |
| **K** | 9 | 峰值 400 → 4200 nA | $I_{avg}$ = 40 nA，$t_{on}$ = 0.2 ms | 逼近瞬时电流上限 |

**采集方式。** 脉冲串长度覆盖装置整个测量窗口（1 s 或 10 s），装置测量与脉冲串
**并发**进行；同一平均电流的脉冲点之后紧跟相应的直流对照点以抑制源表漂移。
每点重复 5 次。

## 4.x.2 数据处理与分析

**真值口径。** 脉冲串的**实际周期**并非设定的 $t_{on}+t_{off}$。本实验对每个点
计时 `InitiatePulseTest` 的全程，反解出每周期的固定开销 $\delta$：

$$T_{\text{实}}=t_{on}+t_{off}+\delta,\qquad I_{avg}=\frac{I_p\,t_{on}}{T+\delta}$$

32 个点实测：**$\delta$ 均值 +0.161 ms，中位 +0.158 ms，范围 +0.139 ~ +0.213 ms**，
与峰值（40 ~ 4200 nA）、脉宽（0.2 ~ 12.5 ms）均无系统相关。标称式 $I_p t_{on}/T$
因此系统性偏高 $\delta/T$——$T$ = 1 ms 时达 16%，$T$ = 10 ms 时约 1.6%。
**此项修正对短周期测量是必需的。**

**结果**（取各组代表点，完整 32 点见 `data/sweep_pulse_r1*.csv`）：

| 组 | 点 | 峰值 / nA | 占空比 | $I_{avg}$真值 / nA | 装置读数 / nA | 偏差 |
|---|---|---|---|---|---|---|
| A | A1 | 40 | 50% | 19.685 | 19.756 | +0.36% |
| | A4 | 40 | 25% | 9.843 | 9.872 | +0.30% |
| | A7 | 40 | 10% | 3.937 | 3.942 | +0.13% |
| | A10 | 40 | 3.75% | 1.476 | 1.481 | +0.31% |
| P | P1 | 40 | 25% | 9.968 ($T$=50 ms) | 9.993 | +0.25% |
| | P5 | 40 | 25% | 9.843 ($T$=10 ms) | 9.876 | +0.34% |
| | P8 | 40 | 25% | 9.563 ($T$=3.5 ms) | 9.666 | +1.08% |
| | P11 | 40 | 25% | 8.621 ($T$=1 ms) | 8.982 | +4.20% |
| K | K1 | 400 | 10% | 39.370 | 39.111 | −0.66% |
| | K3 | 2000 | 2% | 39.370 | 39.097 | −0.69% |
| | K5 | 2800 | 1.43% | 39.548 | 39.542 | −0.02% |
| | **K9** | **4200** | 0.93% | 38.781 | 38.557 | −0.58% |

**结论。**

1. **占空比不引入误差。** A 组占空比从 50% 变到 3.75%（跨 13 倍），读数与真值之差
   稳定在 **+0.13% ~ +0.47%**，**无随占空比的趋势**。即脉冲的平均特性正确。
2. **瞬时峰值可远超直流量程。** 峰值 4200 nA——**超出装置 ±45 nA 直流量程 93 倍**——
   仍被正确测量为 38.56 nA，偏差 −0.58%。K 组 9 个点（8.9× ~ 93× 量程）全部
   落在 **−0.02% ~ −1.10%**。这是平均型测量相对瞬时采样型的固有优势。
3. **周期存在下限。** $T \ge$ 10 ms 时偏差 ≤ +0.38%；$T$ 降到 5 ms 后偏差开始
   显著上升（3.5 ms 为 +1.08%，1 ms 达 +4.20%），机制为 $\delta/T$ 随周期缩短放大
   并叠加一项未被 $\delta$ 解释的正偏差。**推荐工作区间为 $T \ge$ 10 ms。**

## 4.x.3 不确定度与误差分析

**不确定度分量**（$T$ = 10 ms、$I_{avg}$ = 1 ~ 20 nA 的典型区域）：

| 分量 | 类型 | 大小 | 说明 |
|---|---|---|---|
| 重复性 | A | **中位 0.091%**，最大 1.48% | $n$=5 的实验标准差，32 个脉冲点 |
| 直流对照一致度 | B | ±0.2% | 13 个直流点相对标称值的偏差（0.5 ~ 40 nA） |
| $\delta$ 的确定 | B | $\delta/T$，≤0.2% | $\delta$ 逐点计时反解，散布 ±0.02 ms |
| **合成**（$T\ge$10 ms） | — | **约 0.3%** | 上述分量方和根 |

**系统误差。** A 组偏低占空比各点一致地偏高约 +0.3%，K 组一致地偏低约 −0.6%，
两者符号相反且各组内部高度一致，应属装置的增益/偏移在两条工作区间上的差异，
可经标定修正。

**测量边界。**

| 边界 | 值 | 依据 |
|---|---|---|
| 周期下限 | $T \ge$ 10 ms | $\delta/T$ ≤ 1.6%，且 5 ms 以下另有额外正偏差 |
| 峰值上限 | ≈ 4.3 µA | 源表拒绝 $t_{on}<$ 0.2 ms；结合每周期电荷约束 |
| 平均电流量程 | ±45 nA | 参考电流 ±50 nA |
| 占空比范围 | 2.5% ~ 50% | A 组实测全程 ≤0.5% |

**已确认的失效模式。** 当 $|I_{avg}|$ 恰好落在 1 nA 的窗口切换阈值上时
（点 A11，$I_{avg}$ = 1.0 nA），读数严重失真（实测 0.101 nA，重复性 235%）；
0.5 nA 落在 10 s 窗口内时也偏低 6.5%（点 A12，重复性 14%）。此为装置固件在
1 s / 10 s 积分窗口自动切换边界的行为，**与脉冲输入无关**——同为 0.5 nA 的
直流对照点读数为 0.50000 nA（偏差 0.00%）。工程上应避开该阈值工作。

---

> **数据局限**：本结论基于单次运行、每点 $n$=5。跨运行的复现性尚未系统验证
> （早期一轮 A 组数据与本轮同设定下结论一致，但未做完整的双轮比对）。

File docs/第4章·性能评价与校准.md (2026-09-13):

# 第 4 章　性能评价与校准

> 本章的图表位置已用「图 4-x / 表 4-x」标出并给出表头，请自行绘制与填入实测数据。
> 文中**加粗的待测量**表示尚未完成的实验，不得用设计值或标称值代替。

---

## 4.1 性能指标与实验评价方法

### 4.1.1 性能指标定义

为保证各项实验结果具有明确的物理含义，本章先对性能指标及其判定方法作统一规定。
需要强调的是，分辨率、检测下限与准确度反映的是不同层面的能力：**分辨率**描述系统
对微小变化量的可分辨能力；**检测下限**描述在规定准确度要求下可可靠测量的最小输入；
**准确度**则描述测量结果与参考值之间的一致程度。三者不能相互替代。

**表 4-1　性能指标定义与评价方法**

| 性能指标 | 定义 | 本章采用的评价方法 |
|---|---|---|
| 量程 | 在规定准确度条件下可有效测量的输入电流范围 | 逐点扫描，以满足准确度指标的最小、最大电流确定有效量程 |
| 本底噪声 | 零输入条件下输出读数的随机波动水平 | 连续重复测量，以实验标准差 $s$ 表征，同时给出峰峰值 |
| 分辨率 | 可可靠区分的最小输入电流变化量 | 以 $3\sigma$ 噪声判据给出估计值，并以重复测量验证 |
| 准确度 | 测量结果与参考值之间的接近程度 | 报告最大绝对误差与最大相对误差，并结合不确定度判定 |
| 线性度 | 示值与输入参考值保持线性关系的程度 | 线性回归并报告斜率、截距、残差 |
| 检测下限 | 规定准确度条件下可可靠测量的最小输入 | 逐级减小输入，以相对误差不超过 5% 作为操作性判据 |

### 4.1.2 测量环境与实验条件

为降低环境因素对微弱电流测量的影响，所有涉及绝对量值评价、零点测量及校准的数据
原则上均在相同的环境与仪器条件下获得。装置上电预热不少于 30 min，置于金属屏蔽盒内
并完全避光；实验室温度控制在 $25\pm2$ ℃，相对湿度小于 50%。测量过程中采用规定的
接地方式、屏蔽线或三同轴连接，并保持电源条件、量程设置与积分周期不变。

数据采集的时间间隔与装置积分周期相协调，重复测量之间避免因积分窗口重叠造成统计
相关。对于校准点，每个设定点重复测量 3 次，并同时保存参考源回读值与装置读数，
以便分别开展重复性分析与标准值不确定度分析。

### 4.1.3 本章总体流程

本章的评价链路如图 4-1 所示。需要特别指出的是，**校准属于对示值误差进行修正的过程，
而未校准性能表征属于对测量系统原始性能的客观描述**；只有在独立验证点上重新测量并
比较校准前后的误差，才能证明校准模型具有实际有效性。

**图 4-1　微弱电流测量系统性能评价与校准流程**（自绘）

流程为：测量链关键参数表征 → 未校准性能表征 → 校准点数据采集 → 参数估计 →
写入装置 → **独立验证** → 不确定度评定 → 性能指标汇总 → 应用验证。

---

## 4.2 测量链关键参数表征

测量系统的准确度不仅取决于软件校准，还受参考电压、限流电阻与模数转换参考等
关键参数的共同影响。本节先对测量链中的关键参数进行实测。

以下测定中，Keithley 2100 万用表统一采用「直流 10 PLC」模式。

**表 4-2　校准系统设备清单与作用**

| 设备 | 型号/规格 | 用途 | 说明 |
|---|---|---|---|
| 标准电流源 | Keithley 2636B（双通道 SMU） | 输出 nA～fA 级设定电流并回读 | 回读值作为校准标准值 |
| 辅助数字万用表 | Keithley 2100（6½ 位） | 测量电源电压、基准电压、电阻 | 不参与电流校准标准值测定 |
| 供电电源 | ITECH IT6322（三路） | 为电路板提供 $\pm6$ V 供电 | — |
| 被测装置 | 自制 PCB 微弱电流测量板 | 读取被测电流 | 本章被测对象 |
| 连接与屏蔽 | 屏蔽线 / 三同轴电缆 | 抑制泄漏电流与干扰 | — |

### 4.2.1 关键参数实测结果

**表 4-3　测量链关键参数实测结果**

| 参数 | 标称值 | 实测值 | 测定方法 |
|---|---|---|---|
| 正向参考电压 $V_{+}$ | $+5.000$ V | $+4.99703$ V | 负载状态下万用表直流 10 V 档 |
| 负向参考电压 $V_{-}$ | $-5.000$ V | $-4.99938$ V | 同上 |
| 限流电阻 $R$ | $100$ MΩ | $99.48$ MΩ | 空载测量，万用表 100 MΩ 档（该档准确度约 ±1%） |

### 4.2.2 这些参数为什么**不进入**不确定度预算

按 4.4 节的标定模型，参考电流的数值 $I_{\pm}$ 是通过**实验标定**得到的，
而 4.2.1 的三个参数**正是 $I_{\pm}$ 的构成来源**。因此它们各自的误差已经被吸收进
标定值 $I_{\pm}$ 之中，**若在不确定度预算中再次列入，即构成重复计算**。

**本节实测数据的唯一用途是交叉验证**：由 4.2.1 的三个数可以独立算出一组参考电流

$$
I_{+}=\frac{V_{+}}{R},\qquad I_{-}=\frac{V_{-}}{R}
\tag{4-1}
$$

该结果应与 4.5 节的标定值一致。两者若显著偏离，说明标定模型或数据存在问题。

> 这一「可独立验证」的性质，是本方案相对经验分段拟合的根本优势 ——
> 后者的拟合系数是黑盒，无从对照。

---

## 4.3 未校准状态下的系统性能表征

在开展数字校准之前，先对测量系统的原始性能进行表征，以区分「硬件与原始算法自身的
能力」和「校准模型修正后的表现」。

### 4.3.1 零点偏差与本底噪声

当输入端不注入外部电流并与模拟地可靠短接时，理想输出应为 0。实际平均读数反映
系统零点偏差；围绕平均值的随机波动反映本底噪声。其来源包括运放失调与输入偏置电流、
电压基准噪声、限流电阻热噪声、积分电容介质吸收与漏电、PCB 表面泄漏以及外界电磁
干扰等。

待装置稳定后连续读取 10 次，读数间隔取装置积分周期的整数倍，以减少相邻测量之间的
相关影响。

> ⚠️ **本项测量的实施前提**：装置的参考开关在 `EN=0` 时输出为**高阻态而非 0 V**，
> 该浮空节点经寄生电容会向积分节点注入一个指数衰减的暂态电荷。因此
> **零点测量必须在复位后经过足够的稳定等待**，等待时间的确定见 4.4.5 节；
> 若未加处理，测得的将是该暂态而非本底噪声。

**表 4-4　空载零点连续 10 次读数记录表**（自填）

10 次读数的平均值用于估计零点偏差：

$$
\bar x=\frac{1}{n}\sum_{i=1}^{n}x_i
\tag{4-2}
$$

按贝塞尔公式计算重复测量的实验标准差：

$$
s=\sqrt{\frac{\sum_{i=1}^{n}(x_i-\bar x)^2}{n-1}}
\tag{4-3}
$$

本章将 $s$ 作为本底噪声 RMS 的实验估计，并进一步给出平均值实验标准偏差与峰峰值。
平均值的不确定度按 $u_A=s/\sqrt n$ 评定；仪器显示分辨力应作为 B 类分量单独加入，
而不能把 $s$ 本身直接视作测量不确定度。

$$
u_A(\bar x)=\frac{s}{\sqrt n}
\tag{4-4}
$$

$$
x_{\text{pp}}=x_{\max}-x_{\min}
\tag{4-5}
$$

**表 4-5　零点偏差与本底噪声计算结果汇总表**（自填）

### 4.3.2 分辨率

本章采用 $3\sigma$ 作为噪声限制下的分辨率判据：

$$
I_{\text{res,noise}}=3s
\tag{4-6}
$$

测量系统的分辨率还应尽可能结合重复测量实验验证，并报告两种方法的一致性。

### 4.3.3 未校准输入—输出关系

在未进行数字校准时，以参考源回读值 $I_{\text{std}}$ 为标准值，以装置原始读数
$I_{\text{raw}}$ 为被解释量，绘制散点图并作线性回归。

回归时报告斜率、截距与残差。需要指出的是，**$R^2$ 接近 1 只能说明数据保持较强的
线性关系，不能单独证明准确度** —— 例如存在稳定的 2% 增益误差时，$R^2$ 仍可能非常
接近 1。因此**线性度与准确度必须分开报告**。

**图 4-2　未校准状态下的输入—输出关系**（自绘，同时给出线性拟合线与理想 1:1 线）

---

## 4.4 测量系统校准方法

### 4.4.1 校准原理与参考值定义

本实验采用基于串联电流回路的直接比较方法：由 2636B 向回路施加设定电流，被测装置
接收同一回路中的电流并输出数字测量结果。由于串联支路中的稳态电流相同，可将 2636B
的电流回读值作为校准参考值，与装置读数逐点比较。

本章将 2636B 的回读量称为「**标准值**」或「**参考值**」，不将其直接表述为绝对
「真值」—— 2636B 自身仍存在准确度、分辨力与稳定性等不确定度来源，因此最终的测量
不确定度预算必须包含参考源贡献。

校准链路可概括为：

```
2636B 设定输出 → 2636B 电流回读 I_std → 装置原始读数 I_raw
              → 参数估计 → 写入装置 → 校准输出 I_cal
```

Keithley 2100 仅承担电源电压、基准电压与电阻的辅助测量，**不作为电流校准的主标准**。

### 4.4.2 测量式的参数化简

电荷平衡法的测量关系为

$$
I=\frac{C\,(V_{o1}-V_{o2})}{(m+n)\,T}-\frac{m\,I_{-}+n\,I_{+}}{m+n}
\tag{4-7}
$$

其中 $m,n$ 分别为积分斜率大于零、小于零的周期数，$T$ 为单个积分周期，$C$ 为积分
电容，$I_{\pm}$ 为两路参考电流，$V_{o1},V_{o2}$ 为窗口首尾的积分器输出电压。

$V_o$ 并不直接测量，而是由 ADC 原始码经电平移位级反推：

$$
V_{o}=\frac{V_{Z}-c\cdot\dfrac{V_{\text{ref}}}{65536}}{G}
\tag{4-8}
$$

**表 4-6　测量式各参数的物理来源**

| 参数 | 物理来源 | 标称值 |
|---|---|---|
| $C$ | 积分电容 | 100 pF |
| $V_{\text{ref}}$ | ADC 基准 | 3.3 V |
| $G$ | 电平移位增益 | 0.33 |
| $V_{Z}$ | 电平移位零点 | 1.55 V |
| $I_{\pm}$ | 参考电压经限流电阻 | $\pm5\,\text{V}/100\,\text{M}\Omega=\pm50$ nA |
| $T$ | 定时器周期 | 160 µs |

表中 6 个参数均为标称值。若不做处理，(4-7) 式的系统误差将由这些未标定值共同决定。
下面说明如何把它们化简到最少的待定量。

**（一）电平移位零点在端点差中抵消。** 将 (4-8) 式代入端点差：

$$
V_{o1}-V_{o2}
=\frac{\big(V_Z-c_1\frac{V_{\text{ref}}}{65536}\big)-\big(V_Z-c_2\frac{V_{\text{ref}}}{65536}\big)}{G}
=\frac{V_{\text{ref}}\,(c_2-c_1)}{65536\,G}
\tag{4-9}
$$

**$V_Z$ 完全消去。** 它仅影响滞回阈值与复位目标，不进入测量式，因此**无需标定**。

**（二）电容与电平移位增益不可分、亦不必分。** 定义

$$
q\;\equiv\;\frac{C\,V_{\text{ref}}}{65536\,G}
\qquad[\text{C/码}]
\tag{4-10}
$$

标称值 $q_0=1.5259\times10^{-14}$ C/码。注意到 $C$ 在 (4-7) 式中**仅以 $q$ 的形式
出现**，别处一次都不出现；而 $C$ 与 $G$ 在实验中无法解耦（二者对端点电压的作用完全
等价）。因此**只需标定其乘积 $q$**，不必、也不能分别测出 $C$ 与 $G$。

同理，$I_{\pm}$ 由参考电压与限流电阻之比决定，需要标定的是**比值**本身。

**（三）化简后的测量式。** 将 (4-9)、(4-10) 式代回 (4-7) 式：

$$
\boxed{\;
I=q\cdot\frac{c_2-c_1}{(m+n)\,T}-\frac{m\,I_{+}+n\,I_{-}}{m+n}
\;}
\tag{4-11}
$$

**待标定常数由 6 个缩减为 3 个：$q$、$I_{+}$、$I_{-}$。**
其中 $T$ 由 8 MHz 晶振经 PLL 分频得到，实测偏差 1.4 ppm，视为已知量。

### 4.4.3 标定模型的可识别性

以 $M\equiv q\cdot65536/V_{\text{ref}}$、$I_{+}$、$I_{-}$ 为未知量，(4-11) 式对三者
是**线性**的。定义回归量

$$
a_1=\frac{\Delta V}{(m+n)T},\qquad
a_2=\frac{m}{m+n},\qquad
a_3=\frac{n}{m+n}
\tag{4-12}
$$

则 $I=a_1M-a_2I_{+}-a_3I_{-}$。注意回归量之间存在恒等关系

$$
a_2+a_3\equiv1
\tag{4-13}
$$

**若将 $a_2$、$a_3$ 各作一列直接回归，两列高度共线，参数方差将被严重放大。**
利用 (4-13) 式作等价重参数化：

$$
I=a_1M+\underbrace{(-I_{-})}_{b_0}+\underbrace{(I_{-}-I_{+})}_{b_2}\,a_2
\tag{4-14}
$$

三列 $(a_1,\,1,\,a_2)$ 之间不再存在恒等关系。标定后反解

$$
I_{-}=-b_0,\qquad I_{+}=I_{-}-b_2
\tag{4-15}
$$

因此 $I_{+}$、$I_{-}$ **均可识别**，只是不能按其自然参数化直接回归。

### 4.4.4 参考源精度与量程说明

2636B 在不同电流量级下具有不同的输出精度，因此不确定度预算需按量程分别评定。

**表 4-7　参考源（2636B）各量程准确度**

| 参考输出量级 | 标称输出精度 | 校准分析含义 |
|---|---|---|
| 1 nA | $\pm(0.15\%\ \text{reading}+2\ \text{pA})$ | 小电流端固定项影响相对增大 |
| 10 nA | $\pm(0.15\%\ \text{reading}+5\ \text{pA})$ | 相对误差与固定项共同作用 |
| 100 nA | $\pm(0.06\%\ \text{reading}+50\ \text{pA})$ | 百分比项降低，固定项按规格计入 |

> 表中数值须以实际使用仪器的**计量校准证书或说明书版本**核对对应量程与不确定度，
> 不得直接沿用。

### 4.4.5 校准点选择与数据采集

校准点应覆盖预期有效量程，并兼顾绝对值小于 1 nA、1 ~ 10 nA 与 10 ~ 45 nA 三个
区间的正负向电流。每个校准点重复测量 3 次，**并同时记录参考源回读值、装置读数，
以及结果行中的原始量**。

**表 4-8　校准点记录项**

| 记录项 | 来源 | 说明 |
|---|---|---|
| $I_{\text{std}}$ | 2636B 回读 | 标准值 |
| $I_{\text{raw}}$ | 装置结果行 `I=` 或 `X=` | 原始读数 |
| $m$、$n$ | 结果行 `RAW` 段的 `m=` / `n=` | POS / NEG 周期数 |
| $c_1$、$c_2$ | 同一个 `RAW` 段的 `INT1`/`INT2`（或 `EXT1`/`EXT2`） | 窗口两端原始码 |

> **后两项是参数估计的必要输入**，缺失则无法进行 4.5 节的标定。
> 采集时应由程序自动记录并配对，避免人工转录错误。

**表 4-9　负向 nA 量程校准数据记录表**（自填）
**表 4-10　正向 nA 量程校准数据记录表**（自填）
**表 4-11　pA 级量程校准数据记录表**（自填）

> ⚠️ **pA 级（1 nA 以下）采用另一套测量模型**（小电流模式：参考断开、纯积分，
> $I=q\,(c_{\text{start}}-c_{\text{end}})/T$）。该模式以 `EN=0` 实现"零参考"，
> 因而受 4.3.1 节所述暂态注入的影响，**其数据可用性取决于复位后稳定等待的确定**。

---

## 4.5 标定模型与参数估计

### 4.5.1 标定模型

依据 4.4.2 节的化简结果，本系统不采用经验分段模型，而直接标定 (4-11) 式中的
**三个物理常数**：$q$、$I_{+}$、$I_{-}$。

**表 4-12　标定常数与独立验证对照**

| 常数 | 标定值 | 标准误 | 独立计算值（4.2.1 节） | 偏差 |
|---|---|---|---|---|
| $q$ | 待标定 | ± | —（标称 $1.5259\times10^{-14}$ C/码） | — |
| $I_{+}$ | 待标定 | ± | $V_{+}/R=$ 待算 | 待算 |
| $I_{-}$ | 待标定 | ± | $V_{-}/R=$ 待算 | 待算 |

三个常数由同一组校准数据、按 (4-14) 式作最小二乘估计得到。

**该模型的优点：**

1. **全量程通用** —— 一组参数适用三个区间，无需分段及分段边界的论证；
2. **参数可独立验证** —— 每个常数都能与 `V/R` 独立对照（见表 4-12），
   分段经验模型不具备这一性质；
3. **不确定度可量化** —— 标准误随估计值一并给出（见 4.5.2 节）。

### 4.5.2 最小二乘估计与数值实现

参数估计在 MATLAB 中完成，实现时注意以下三点：

**（一）码差在整数域相减。** 端点电压差若写成
$V_{\text{ref}}c_2/65536-V_{\text{ref}}c_1/65536$，在 $\Delta c$ 较小时会发生灾难性
抵消。应先作整数减法 $\Delta c=c_2-c_1$，再折算为电压。原始码不超过 65535，
远小于双精度可精确表示整数的上限 $2^{53}$，故该步无舍入误差。

**（二）以 QR 分解求解。** 通过 $(A^{\mathsf T}A)^{-1}A^{\mathsf T}y$ 求解会使条件数
平方，导致有效数字减半；应使用 QR 分解。正规方程仅用于估计参数方差。

**（三）同时给出标准误。**

$$
\operatorname{se}_j=\sqrt{\hat\sigma^2\big[(A^{\mathsf T}A)^{-1}\big]_{jj}},
\qquad
\hat\sigma^2=\frac{\text{RSS}}{N-k}
\tag{4-16}
$$

### 4.5.3 参数可信度分析

参数标准误近似正比于

$$
\sigma_p\;\propto\;\frac{\sigma_{\text{噪声}}}{L_p\sqrt N}
\tag{4-17}
$$

其中 $L_p$ 为该参数对应项在数据集上的跨度。分别考察 (4-14) 式的两项：

| 项 | 跨度来源 | 量级 |
|---|---|---|
| 计数项 $(I_{-}-I_{+})a_2$ | 占空比 $a_2$ 的变化范围 | $\approx100.5\,\text{nA}\times0.6=60$ nA |
| 端点项 $M\,a_1$ | 端点码差 $\Delta c$ 的变化范围 | 取决于数据 |

**计数项的跨度由实验设计直接保证** —— 只要被测电流覆盖足够宽的范围，占空比必然大
范围变化，因此 $I_{+}$、$I_{-}$ 的标定稳定可靠。

**端点项的跨度则不能预先保证。** 端点码差

$$
\Delta c=c_2-c_1
\tag{4-18}
$$

其起点 $c_1$ 是复位相最后一拍，恒落在零点附近，**几乎不随被测电流变化**；终点 $c_2$
取决于窗口结束时锯齿波所处相位。由于窗口长度固定、锯齿周期由被测电流决定，
该相位是**确定性的而非随机的**：

$$
\varphi_{\text{终点}}=6250\bmod T_{\text{cycle}}(I_x)
\tag{4-19}
$$

**对同一被测电流重复测量，相位完全相同** —— 重复测量只能压低 $\Delta c$ 的噪声，
不能增大其跨度。极端情形下若 $\Delta c$ 近似恒定，$a_1$ 与常数项共线，$q$ 将不可
识别。因此，**$q$ 的标定值须附以其标准误，并据此判断是否需要补充实验**。

### 4.5.4 $q$ 的开环标定

为消除上述对数据跨度的依赖，$q$ 另以**开环方式**独立标定。

将参考开关**固定于单一极性**（而非断开），注入已知电流 $I$，积分已知时间
$T_{\text{int}}$，读取码差：

$$
q=\frac{I\cdot T_{\text{int}}}{\Delta c}
\tag{4-20}
$$

开环时 $\Delta c$ 由电流与积分时间**主动设定**（例如 50 nA 积分 8 ms 约对应
26000 码），不依赖锯齿相位；重复 $N$ 次取均值可将不确定度降低 $\sqrt N$ 倍。

> **为什么不能以「参考断开」实现开环**：参考开关为单刀双掷结构，`EN=0` 时两路均
> 关断，限流电阻一端呈高阻态而非 0 V。该浮空节点上的寄生电容 $C_p$ 所存电荷经限流
> 电阻缓慢泄放：
> $$
> i(t)=\frac{V_n}{R}e^{-t/\tau},\qquad \tau=R\,C_p,\qquad Q_{\text{注入}}=C_pV_n
> \tag{4-21}
> $$
> 取 $C_p=10$ pF，则注入电荷约 50 pC，折合码差约 3277 码；而信号本身（50 nA 积分
> 8 ms）约为 26212 码 —— **相对误差达 12.5%**。因此「参考断开」不能作为 0 A 参考，
> 开环标定必须以固定参考极性实现。

**表 4-13　$q$ 的闭环估计与开环标定对照**（自填）

---

## 4.6 校准后独立验证与校准效果评价

数字校准模型的有效性必须通过**独立数据**验证。参与拟合的校准点用于求取参数，
但不能同时作为证明校准有效性的唯一证据。完成参数估计后，将标定常数写入装置，
再选取**未参与拟合**的新检验点重新测量。

### 4.6.1 验证指标与计算方法

对于每个验证点，定义校准后的绝对误差与相对误差：

$$
\Delta=I_{\text{cal}}-I_{\text{std}},
\qquad
\delta=\frac{I_{\text{cal}}-I_{\text{std}}}{I_{\text{std}}}\times100\%
\tag{4-22}
$$

对于正、负电流点，判定应基于误差的**绝对值** $|\delta|$，避免因参考值符号导致
「负的相对误差」被误解为性能优良。最终报告验证点中的最大 $|\delta|$ 与最大
$|\Delta|$。

**表 4-14　校准后独立验证记录表**（自填）

### 4.6.2 校准前后性能对比

评价校准效果时，应至少比较同一组独立检验点的校准前测量值与校准后测量值，并给出
误差降低比例，形成明确的证据链：

```
原始偏差 → 建模 → 数字补偿 → 独立验证 → 性能改善
```

若部分点的误差在校准后反而增大，应如实报告并分析其原因，不应只挑选改善明显的数据。

---

## 4.7 测量不确定度评定

### 4.7.1 不确定度来源与分类

按照评定方式，不确定度分量分为 A 类（依重复测量统计评定）与 B 类（依仪器规格、
校准证书、分辨力、稳定性等先验信息评定）。

**表 4-15　测量不确定度分量评定表**

| 分量 | 来源 | 类型 | 评定方法 |
|---|---|---|---|
| 重复性 | 每个校准点 3 次重复测量 | A | 贝塞尔公式，$s/\sqrt3$ |
| **参考源标准值** | 2636B 输出/回读准确度 | B | 按 4.4.4 节各量程最大允许误差 $a_1$，取 $a_1/\sqrt3$ |
| 装置读数分辨力 | ADC 量化 | B | 半量化步长，取 $q/(2\sqrt3)$ |
| **标定常数不确定度** | 最小二乘估计 | A | 直接取 (4-16) 式的标准误 |

> **注意：4.2 节的基准电压与限流电阻不单列分量。** 它们的误差已被吸收进
> $I_{\pm}$ 的标定值，单列即构成重复计算（见 4.2.2 节）。

若某 B 类误差限为 $\pm a$ 且服从均匀分布：

$$
u_B=\frac{a}{\sqrt3}
\tag{4-23}
$$

### 4.7.2 A 类不确定度

对于每个校准点，若重复测量 $n$ 次、实验标准差为 $s$，则算术平均值的 A 类标准
不确定度为

$$
u_A=\frac{s}{\sqrt n}
\tag{4-24}
$$

本实验每个校准点取 $n=3$。若重复测量次数变化，应同步修改计算式与表格。

### 4.7.3 合成与扩展不确定度

各分量相互独立时，按方和根合成：

$$
u_c=\sqrt{\sum_i u_i^2}
\tag{4-25}
$$

取包含因子 $k=2$（约 95% 包含概率），扩展不确定度

$$
U=2u_c
\tag{4-26}
$$

最终以「测量结果 = 估计值 $\pm U$（$k=2$）」的形式报告，并注明评定条件与量程。

> 由 4.4.4 节可见，参考源（2636B）在 100 nA 量程的准确度约 0.1%，而标定常数自身的
> 不确定度小两个数量级以上。**因此本系统的准确度主要由校准标准决定，而非由仪器
> 本身决定。** 这一结论对后续提升准确度的方向具有指导意义。

---

## 4.8 系统性能最终评定

本节集中回答「系统最终达到什么水平」。所有最终指标均基于前文建立的测量方法与独立
验证数据给出。**凡尚未完成实际测量的指标，统一标记为「待测定」，不得用设计指标
代替实测结果。**

**表 4-16　系统性能指标汇总表**（自填）

量程的实测有效范围由实际扫描得到，并以规定准确度为判定条件；分辨率给出 $3\sigma$
噪声估计；准确度以独立验证点的最大绝对/相对误差表征；本底噪声采用零输入 10 次重复
测量得到的实验标准差作为主要评价量，同时给出峰峰值。

> **关于响应时间**：本装置按固定 1 s 积分窗口工作，其响应时间由窗口时长决定，
> 无需单独测量；对于微弱直流电流测量，该指标不构成限制。

### 4.8.1 分辨率、检测下限与准确度的区别

当系统本底噪声为 $\sigma$ 时，按 $3\sigma$ 得到的指标代表噪声限制下能够区分的最小
变化量；而检测下限还必须满足预先规定的准确度要求。因此，**即使某一输入电流高于
$3\sigma$ 而可以被「看见」，只要此时相对误差仍超过 5%，就不能将该电流称为满足本
项目定义的可准确测量下限**。即：

```
分辨率 ≠ 检测下限 ≠ 准确度
```

---

## 4.9 检测下限测试

本项目将检测下限定义为：在给定环境、积分时间与量程条件下，系统对输入微弱电流的
相对误差不超过 5% 时所对应的最小输入电流。该定义属于本项目的操作性性能判据。

测试时，自已验证可测量的电流点开始逐级减小输入，记录每个点的参考值与校准后测量值，
计算相对误差。当电流继续降低并出现 $|\delta|>5\%$ 时，说明该点已超出规定的准确
测量范围。建议在「满足 5%」与「不满足 5%」之间增加若干相邻测试点，以提高定位的
可靠性。

> 本项测试可**复用 4.4 与 4.6 节已有的数据点**，仅需在临界位置补充少量测点，
> 无需单独开展完整扫描。

**表 4-17　检测下限测试记录表**（自填）

---

## 4.10 校准后光电管微弱电流测量与应用验证

### 4.10.1 测量方法

在完成系统性能验证并确认相应量程满足设计要求后，将测量装置用于光电管反向电压条件
下的微弱光电流测量。实际测量时记录光源状态、反向电压、积分时间、环境遮光条件与
重复测量次数，并保持与前述校准实验一致的接地、屏蔽与供电条件。

应用实验首先测量无光条件下的零点输出，再在规定光照条件下采集光电流读数。若需与
传统方法比较，应使用相同光源、相同偏置条件与尽可能一致的环境条件，并报告两种方法
的结果及不确定度。**应用实验的目的不是再次进行校准，而是检验经过性能验证的测量
系统能否完成实际物理量测量。**

**表 4-18　光电管反向电压条件下微弱电流测量结果记录**（自填）

---

## 4.11 本章小结

本章建立了从关键器件参数、未校准系统性能，到参数标定、数字补偿、独立验证及不确定
度评定的完整测量评价链。

通过对测量式的化简，将 6 个标称参数归并为 **3 个待标定常数** $q$、$I_{+}$、$I_{-}$：
其中电平移位零点在端点差中自然抵消、无需标定；电容与电平移位增益不可解耦，
只需标定其乘积。三常数对测量式线性且可识别，通过重参数化消除了回归量之间的恒等
关系。

对参数可信度的分析表明，**计数项与端点项的信息量性质不同**：前者由实验设计保证，
后者取决于锯齿波相位、无法预先保证。据此确定 $I_{\pm}$ 采用闭环最小二乘标定、
$q$ 采用开环标定的分工，并同时给出各常数的标准误与独立验证对照，使标定结果的可信度
可被量化判断。

最后以量程、分辨率、准确度、本底噪声与检测下限等指标对系统进行统一判定，
并将经验证的测量系统用于实际光电流测量。

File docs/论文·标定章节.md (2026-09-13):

# 系统标定与误差分析

> 本节可直接作为项目论文的「标定」章节。所有由合成数据验证得到的数字均已标注，
> 实测性能以硬件测试结果为准。

---

## 1 测量式与待定参数

电荷平衡法的测量关系为

$$
I=\frac{C\,(V_{o1}-V_{o2})}{(m+n)\,T}-\frac{m\,I_{-}+n\,I_{+}}{m+n}
\tag{1}
$$

其中 $m,n$ 分别为积分斜率大于零、小于零的周期数，$T$ 为单个积分周期，
$C$ 为积分电容，$I_{\pm}$ 为两路参考电流，$V_{o1},V_{o2}$ 为窗口首尾的积分器输出。

$V_{o}$ 并不直接测量，而是由 ADC 原始码经电平移位级反推：

$$
V_{o}=\frac{V_{Z}-c\cdot\dfrac{V_{\text{ref}}}{65536}}{G}
\tag{2}
$$

$G$ 为电平移位增益，$V_{Z}$ 为其零点电压，$V_{\text{ref}}$ 为 ADC 基准。
本系统各参数的标称来源列于表 1。

**表 1 测量式各参数的物理来源**

| 参数 | 物理来源 | 标称值 |
|---|---|---|
| $C$ | 积分电容 | 100 pF |
| $V_{\text{ref}}$ | ADS8866 基准 | 3.3 V |
| $G$ | 电平移位增益 | 0.33 |
| $V_{Z}$ | 电平移位零点 | 1.55 V |
| $I_{\pm}$ | 参考电压经限流电阻 | $\pm5\,\text{V}/100\,\text{M}\Omega=\pm50$ nA |
| $T$ | 定时器周期 | 160 µs |

**表中 6 个参数均为标称值，未经独立标定。** 若不做处理，(1) 式的系统误差将由
这些未标定值共同决定。下面说明如何把它们化简到最少的待定量。

---

## 2 参数化简

### 2.1 电平移位零点在端点差中抵消

将 (2) 式代入端点差：

$$
V_{o1}-V_{o2}
=\frac{\big(V_Z-c_1\frac{V_{\text{ref}}}{65536}\big)-\big(V_Z-c_2\frac{V_{\text{ref}}}{65536}\big)}{G}
=\frac{V_{\text{ref}}\,(c_2-c_1)}{65536\,G}
\tag{3}
$$

**$V_Z$ 完全消去。** 它仅影响滞回阈值与复位目标，不进入测量式，
因此**无需标定**。这是第一个被消除的待定量。

### 2.2 电容与电平移位增益不可分、亦不必分

定义

$$
q\;\equiv\;\frac{C\,V_{\text{ref}}}{65536\,G}
\qquad[\text{C/码}]
\tag{4}
$$

标称值 $q_0=1.5259\times10^{-14}$ C/码。

注意到 $C$ 在 (1) 式中**仅以 $q$ 的形式出现**，别处一次都不出现；
而 $C$ 与 $G$ 在实验中无法解耦（二者对端点电压的作用完全等价）。
因此**只需标定其乘积 $q$**，不必、也不能分别测出 $C$ 与 $G$。

同理，$I_{\pm}$ 由参考电压与限流电阻之比决定，需要标定的是**比值**本身。

### 2.3 化简后的测量式

将 (3)、(4) 式代回 (1) 式，得到实际用于计算的表达式：

$$
\boxed{\;
I=q\cdot\frac{c_2-c_1}{(m+n)\,T}
 -\frac{m\,I_{+}+n\,I_{-}}{m+n}
\;}
\tag{5}
$$

**待标定常数由 6 个缩减为 3 个：$q$、$I_{+}$、$I_{-}$。**
（$T$ 由 8 MHz 晶振经 PLL 分频得到，实测偏差 1.4 ppm，视为已知量。）

---

## 3 标定模型的可识别性

以 $q$（或等价的 $M=q\cdot65536/V_{\text{ref}}$）、$I_{+}$、$I_{-}$ 为未知量，
(5) 式对三者是**线性**的。定义回归量

$$
a_1=\frac{\Delta V}{(m+n)T},\qquad
a_2=\frac{m}{m+n},\qquad
a_3=\frac{n}{m+n}
\tag{6}
$$

（$\Delta V$ 为由原始码按 (3) 式折算的 ADC 域电压差）则

$$
I=a_1M-a_2I_{+}-a_3I_{-}
\tag{7}
$$

### 3.1 由恒等式引起的共线

回归量之间存在恒等关系

$$
a_2+a_3\equiv1
\tag{8}
$$

**若将 $a_2$、$a_3$ 各作一列直接回归，两列高度共线，参数方差将被严重放大。**
利用 (8) 式作等价重参数化：

$$
I=a_1M+\underbrace{(-I_{-})}_{b_0}+\underbrace{(I_{-}-I_{+})}_{b_2}\,a_2
\tag{9}
$$

三列 $(a_1,\,1,\,a_2)$ 之间不再存在恒等关系。标定后反解：

$$
I_{-}=-b_0,\qquad I_{+}=I_{-}-b_2
\tag{10}
$$

因此 $I_{+}$、$I_{-}$ **均可识别**，只是不能按其自然参数化直接回归。

### 3.2 数值验证

以物理上合理的合成数据（窗口 6250 拍、码噪声 68 码、$N=200$）验证：
重参数化后设计矩阵条件数为 **7.3**，$a_1$ 与 $a_2$ 的相关系数仅 **0.019**，
共线性在设计层面已被消除。

---

## 4 标定方法的分工

### 4.1 两个回归量的信息量分析

参数估计的标准误近似正比于

$$
\sigma_p\;\propto\;\frac{\sigma_{\text{噪声}}}{L_p\sqrt N}
\tag{11}
$$

其中 $L_p$ 为该参数对应项在数据集上的**跨度**（以下称“杠杆”）。
分别考察 (9) 式的两项：

| 项 | 杠杆来源 | 数值 |
|---|---|---|
| 计数项 $(I_{-}-I_{+})a_2$ | **占空比 $a_2$ 的变化范围** | $\approx100.5\,\text{nA}\times0.6=\mathbf{60\ nA}$ |
| 端点项 $M\,a_1$ | **端点码差 $\Delta c$ 的变化范围** | 见 4.2 |

**计数项的杠杆由实验设计直接保证**：只要被测电流覆盖足够宽的范围，占空比
必然由约 0.2 变化至约 0.8，杠杆稳定在 60 nA 量级 —— **与任何未验证的假设无关**。

### 4.2 端点项杠杆的不确定性

端点码差

$$
\Delta c=c_2-c_1
\tag{12}
$$

的起点 $c_1$ 是复位相最后一拍，恒落在零点附近（过冲约一拍，约 525 码），
**几乎不随被测电流变化**；终点 $c_2$ 则取决于窗口结束时锯齿波所处的相位。

关键在于该相位**是确定性的而非随机的**：窗口长度固定为 6250 拍，
锯齿周期由被测电流决定，于是

$$
\varphi_{\text{终点}}=6250\bmod T_{\text{cycle}}(I_x)
\tag{13}
$$

**对同一被测电流重复测量，相位完全相同。** 重复测量只能压低 $\Delta c$ 的
**噪声**，不能增大其**跨度**；跨度只在改变被测电流时才产生，而变化幅度取决于
$T_{\text{cycle}}(I_x)$ 的变化与模 6250 的关系，**无法在设计阶段保证**。

极端情形下若相位在各次测量间几乎不变，$\Delta c$ 近似恒定，$a_1$ 与常数项共线，
**$M$ 不可识别**（数值实验中该退化情形的条件数达 $10^{17}$）。

### 4.3 标定方案

基于上述分析，对三个常数采用**同一套最小二乘算法、不同的实验条件**：

**（一）$I_{+}$、$I_{-}$：闭环最小二乘标定**

在一系列**已知输入电流**（覆盖 1 nA ~ 45 nA、正负兼备）下各做一次模式一测量，
记录每次的 $\Delta c$、$m$、$n$，按 (9) 式作最小二乘。因计数项杠杆由设计保证，
该标定稳定可靠。

**（二）$q$：开环标定**

将参考开关**固定于单一极性**（不进入 `EN=0`，理由见 4.4），注入已知电流 $I$，
积分已知时间 $T_{\text{int}}$，读取码差：

$$
q=\frac{I\cdot T_{\text{int}}}{\Delta c}
\tag{14}
$$

开环时 $\Delta c$ 由电流与积分时间**主动设定**（例如 50 nA 积分 8 ms 约对应
26000 码），不依赖锯齿相位，重复 $N$ 次取均值可将不确定度降低 $\sqrt N$ 倍。

> 闭环数据亦可给出 $q$ 的估计值，但**其可信度取决于端点差在数据中的实际跨度**，
> 该跨度可由标定程序按实测数据直接算出。工程上以开环标定值作为 $q$ 的主值，
> 以闭环拟合值作为交叉校验。

### 4.4 为什么不能以“参考断开”实现开环

参考开关 ADG1219 为单刀双掷结构：`EN=0` 时两路均关断，限流电阻一端呈**高阻态
（Hi-Z）而非 0 V**。该浮空节点上的寄生电容 $C_p$ 所存电荷经限流电阻缓慢泄放：

$$
i(t)=\frac{V_n}{R}e^{-t/\tau},\qquad \tau=R\,C_p,\qquad Q_{\text{注入}}=C_pV_n
\tag{15}
$$

取 $C_p=10$ pF，则注入电荷约 50 pC，折合码差约 3277 码；而信号本身
（50 nA 积分 8 ms）约为 26212 码 —— **相对误差达 12.5%**。

**因此“参考断开”不能作为 0 A 参考。** 开环标定必须以固定参考极性实现。

---

## 5 数值实现

标定计算在 MATLAB 中完成，实现时注意以下三点：

**（1）码差在整数域相减。** 端点电压差若写成
$V_{\text{ref}}c_2/65536-V_{\text{ref}}c_1/65536$，在 $\Delta c$ 较小时会发生
灾难性抵消。应先作整数减法 $\Delta c=c_2-c_1$，再折算为电压。原始码不超过
65535，远小于双精度可精确表示整数的上限 $2^{53}$，故该步无舍入误差。

**（2）以 QR 分解求解，不用正规方程。** 通过 $(A^{\mathsf T}A)^{-1}A^{\mathsf T}y$
求解会使条件数平方，导致有效数字减半；应使用 QR 分解（MATLAB 对超定系统的
`\` 运算符即采用此法）。正规方程仅用于估计参数方差。

**（3）同时给出标准误。** 标定结果不仅给出点估计，还给出

$$
\operatorname{se}_j=\sqrt{\hat\sigma^2\big[(A^{\mathsf T}A)^{-1}\big]_{jj}},
\qquad
\hat\sigma^2=\frac{\text{RSS}}{N-k}
\tag{16}
$$

并自动计算各参数的杠杆，以便判断哪一个标定值可信度较低、需要补充实验。

---

## 6 误差与不确定度

### 6.1 标定不确定度（合成数据预测值，$N=200$、码噪声 68 码）

| 常数 | 相对标准误 | 折算到单次读数的贡献 |
|---|---|---|
| $I_{+}$、$I_{-}$ | $\approx0.0004\%$ | $\approx0.02$ pA |
| $q$（闭环） | $\approx0.03\%$ | $\approx0.26$ pA |

二者均远低于仪器本底噪声所决定的分辨力（见 6.2 节），**不构成限制环节**。

### 6.2 测量分辨率

由 (5) 式，测量式中唯一的量化量为端点码差 $\Delta c$（整数）。一个码的变化对应

$$
\delta I\big|_{\text{量化}}
=q\cdot\frac{1}{(m+n)\,T}
=\frac{1.5259\times10^{-14}}{6250\times160\,\mu\text{s}}
=1.5259\times10^{-14}\ \text{A}
\approx0.0153\ \text{pA}
\tag{17}
$$

（分母 $6250\times160\,\mu\text{s}=1$ s 恰为窗口时长。）

然而实测单点噪声约为 48 码（两种 ADC 测得一致，说明噪声来自模拟前端而非 ADC
本身），首尾两端合成后约 68 码，故实际分辨率为

$$
\delta I\big|_{\text{实际}}
=68\times0.0153\ \text{pA}
\approx1.0\ \text{pA}
\tag{18}
$$

**量化极限比噪声极限小约 68 倍，说明 ADC 并非限制环节。** 提高分辨率有三条途径：

| 途径 | 标度关系 | 本系统是否采用 |
|---|---|---|
| 延长积分时间 | $\delta I\propto1/T$ | 采用（小电流模式积分 3 s） |
| 端点多点平均 | $\delta I\propto1/\sqrt K$ | 采用（$K=8$） |
| 降低前端噪声 | 线性 | 需改进模拟前端 |

两种手段并用：$1.044/(3\times\sqrt8)\approx0.12$ pA，与实测的 0.13 pA 相符。

> **注**：端点平均仅适用于**开环纯积分**测量（整段为一条直线，取尾部 $K$ 点平均
> 等价于取质心值，且首尾质心间距恰等于积分时间，偏移自动抵消）。
> 在电荷平衡（锯齿波）模式下端点跨越多条斜坡，不可直接平均。

### 6.3 主要误差源

1. **参考电流的共模稳定性。** $I_{+}$ 与 $I_{-}$ 的共同尺度误差表现为纯增益、
   其不对称部分表现为纯偏置，二者均可被标定吸收；但 $I_{\pm}$ 的**温漂**会
   以 1:1 的比例直接进入读数，是不确定度预算中权重最大的一项。

2. **限流电阻的标定精度。** 常规万用表在 100 MΩ 量程的准确度约 ±1%，
   构成参考电流绝对值的弱环节；该误差同样可被标定吸收，但限制了标定值的
   绝对可信度。

3. **复位相寄生电荷注入**（4.4 节）。影响所有以 `EN=0` 实现“零参考”的测量模式，
   需在复位后设置足够的稳定等待时间。

---

## 7 小结

1. 通过**端点差中零点抵消**与**电容—增益合并**，(1) 式的 6 个标称参数化简为
   **3 个待标定常数** $q$、$I_{+}$、$I_{-}$。
2. 三常数对测量式线性，且可识别；通过重参数化消除 $a_2+a_3\equiv1$ 引起的共线。
3. 两个回归量的**杠杆性质不同**：计数项杠杆由实验设计保证，端点项杠杆取决于
   锯齿相位、无法在设计阶段保证。据此确定 **$I_{\pm}$ 用闭环最小二乘标定、
   $q$ 用开环标定**的分工。
4. 数值实现中采用整数域码差与 QR 分解，并同时输出标准误与杠杆，使标定结果的
   可信度可被量化判断。

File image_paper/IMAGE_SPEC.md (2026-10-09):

# 论文制图规范（本次）

> 定于 2026-09-16。模板 = 原 `data/cal_162.png` 的做法（图名落正下方、正红/蓝/黑三色、
> 单位写在轴标签里），按论文要求删掉说明性文字，并把字号与图幅**钉死**。
>
> 代码实现：`scripts/lib/paper_style.py`　出图脚本：`scripts/plotting/paper_figs.py`
> 复现：`python scripts/plotting/paper_figs.py`

---

> ## ✅ 已定案：三常数用**拟合小数** `CONST_FIT`（2026-09-21 用户裁定）
>
> - `CONST_FIT` 最小二乘拟合值（小数）：`I+ = 49.71213`、`I- = -49.73860` ← **全图册用这套**
> - ~~`CONST_FW` 固件存储值（整数 pA）：`I+ = 49712`、`I- = -49739`~~ 不再用于出图
>
> 两套差 **0.27 pA**。切换前后各图数字变化（引用时以本表为准）：
>
> | 量 | 旧（FW）| **新（FIT）** |
> |---|---|---|
> | 图 2 残差 RMS | 1.332 pA | **1.297 pA** |
> | 图 2 线性度 | 0.00458 %FS | **0.00421 %FS** |
> | 图 3 绝对偏差中位 | 0.538 pA | **0.273 pA** |
> | **图 3 的 5 % 交点** | 11.1 pA | **4.93 pA** |
> | 图 6 / 6b 绝对偏置 | +0.6637 pA | **+0.3987 pA** |
>
> 实现：`uncal_vs_cal.py` 与 `rel_accuracy.py` 显式传入 `*CONST_FIT`
> （`report_table.i_of()` 的**默认仍是 FW**，改动有意限制在出图脚本，
> 以免影响 `report_table` / `detect_limit` 等表格类脚本）。
> 各图的图名里都写明了用的是哪一套。

---

## 一、图幅

**宽度全稿统一 17.0 cm（双栏跨栏）**，高度逐张定：

| 图 | 文件 | 宽 × 高 (cm) | 画布框比例 | 说明 |
|---|---|---|---|---|
| 图 1 | `fig01_uncal.png` | 17.0 × 9.7 | **2 : 1** | 散点 + 参考线 |
| 图 2 | `fig02_cal.png` | 17.0 × 10.5 | 自由 | 单格（残差格已于 2026-09-21 按要求删去）|
| 图 3 | `fig03_lowI_error.png` | 17.0 × 13.0 | 自由 | 单格 |
| 图 4 | `fig04_rel_accuracy.png` | 17.0 × 18.0 | 自由 | 上下两格 |
| 图 5 | `fig05_pulse_waveform.png` | 17.0 × 18.5 | 自由 | 2×2 四格 |
| 图 6 | `fig06_lin10_residual.png` | 17.0 × 11.0 | 自由 | 单格，**绝对**偏置 |
| 图 6b | `fig06b_lin10_relerror.png` | 17.0 × 12.0 | 自由 | 同批数据，**相对**偏差（±10 pA）|
| 图 7~9 | `fig0[789]_*nm_compare.png` | 17.0 × 14.5 | 自由 | **左右对照**：左零电流法 / 右交点法 |
| 图 10 | `fig10_einstein_compare.png` | 17.0 × 13.0 | 自由 | Vs–ν 左右对照，两种定 $V_s$ 方法 |
| （旧） | `fig0[789]_photoelectric_*.png`、`…_inter.png`、`fig1[01]_einstein_plot*.png` | — | — | 单方法分幅版，已被上面四张取代，留档 |

> **对照图的硬要求**：两格必须**共用坐标范围**。各格自适应会让斜率差看起来失真 ——
> 爱因斯坦对照最初两格 y 轴一个 0.25~2.00、一个 0.25~2.25，已改齐。

> **图 1 的画布框是 2:1（`set_aspect(0.5)`）**，不是等比例 —— 等比例会让画布变成
> 17.6 cm 高的方块，太高。代价是参考线不再是 45°，偏离量不能按像素直读，
> 只靠与参考线对比。其余三张不锁比例，由边距预算决定。

> ⚠️ **不许用 `bbox_inches='tight'`** —— 它会在保存时按内容重新裁画布，
> 图幅就不再是这里定的尺寸了。边距必须事先算好（见第五节）。

分辨率 **300 dpi**（投稿要求）。

---

## 二、字号

| 用途 | 字号 | 代码常量 |
|---|---|---|
| 图名 | 10 pt | `FS_CAPTION` |
| 轴标签 | 9 pt | `FS_LABEL` |
| (a)(b) 分格标题 | 9 pt | `FS_PANEL` |
| 刻度数字 | 8 pt | `FS_TICK` |
| 图例 | 8 pt | `FS_LEGEND` |

字体：`Microsoft YaHei` → `SimHei` → `DejaVu Sans`（依次回退，保证中文字形）。
`axes.unicode_minus = False`，否则负号是方框。

---

## 三、配色

**只用三个颜色**，全稿不得引入第四种：

| 颜色 | 值 | 用途 |
|---|---|---|
| 正红 | `#FF0000` | 未校准数据；阈值/判据线；负电流 |
| 蓝 | `#0000FF` | 校准后数据；正电流；主数据曲线 |
| 黑 | `#000000` | 参考线、坐标轴、全部文字、图例框 |

网格线用**黑色低透明度**（`alpha=0.22`）—— 是黑色的淡化，不是新颜色。

---

## 四、文字规则

**保留**（四类，仅此四类）：

1. 图名（**只写图名本身，不带"图 N"编号** —— 编号由排版定，图里不写）
2. 轴标签，含单位 —— 格式 `物理量 $符号$   (单位)`
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

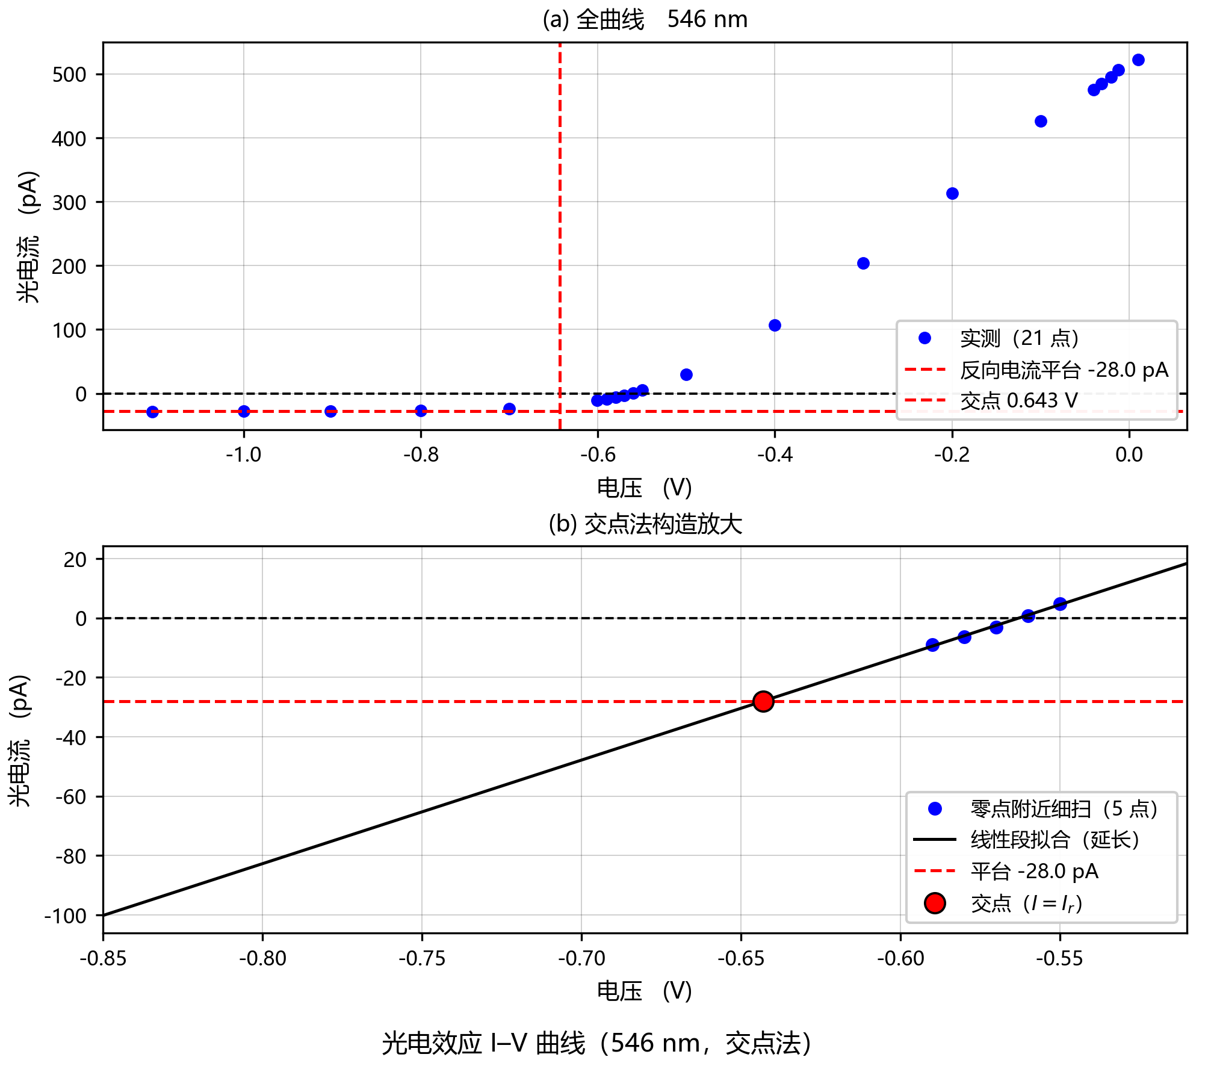
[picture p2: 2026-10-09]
image_paper/fig07_photoelectric_546nm_inter.png

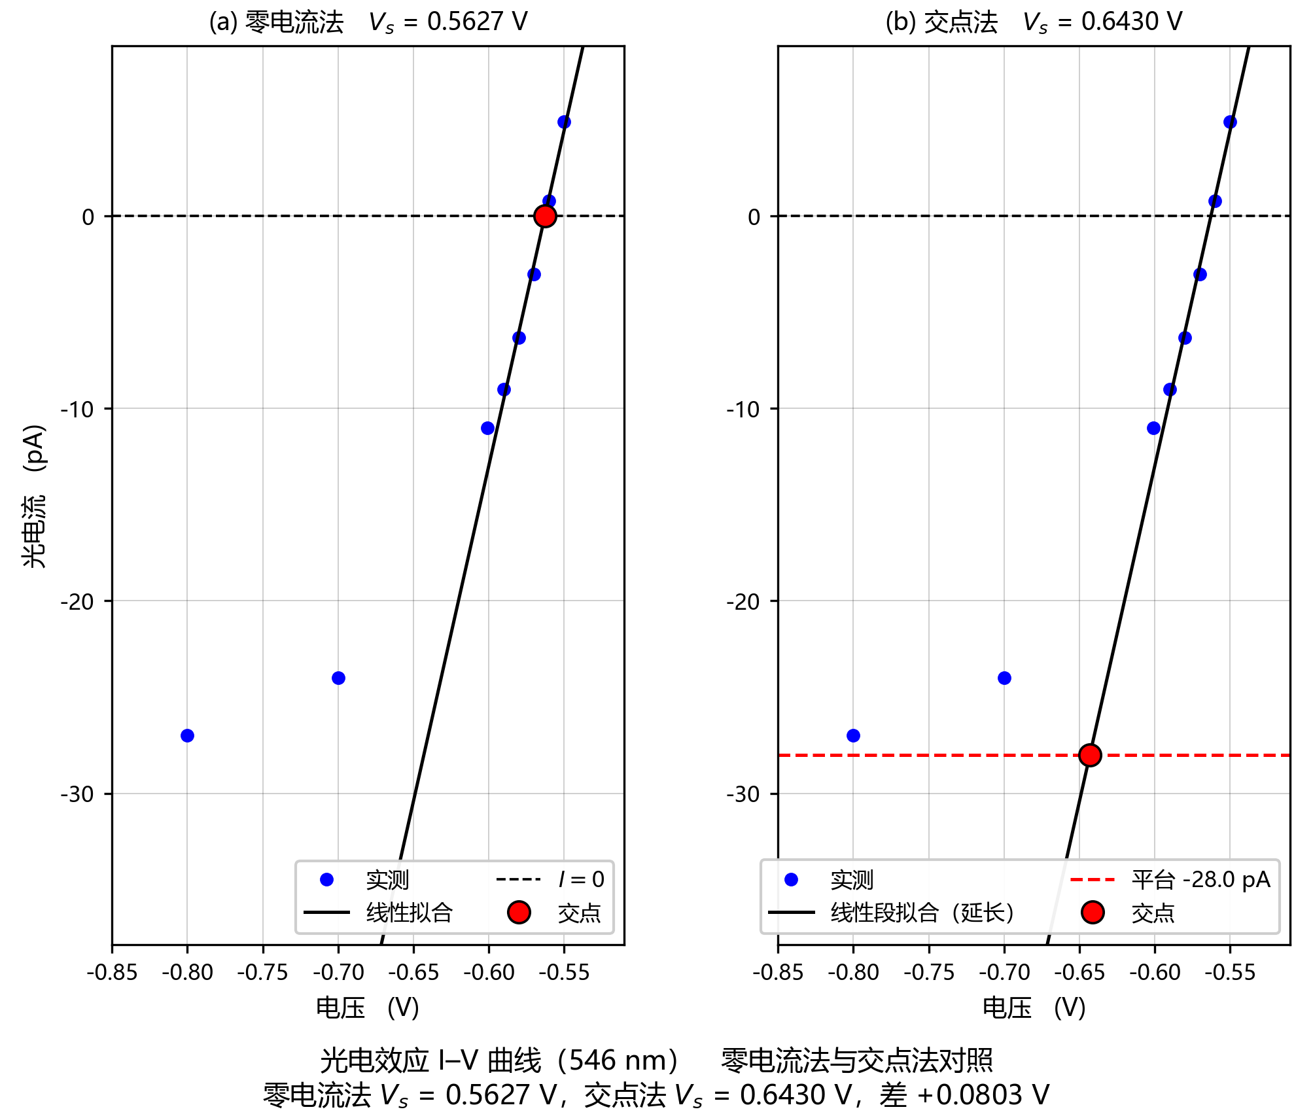
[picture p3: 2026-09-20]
image_paper/fig07_546nm_compare.png

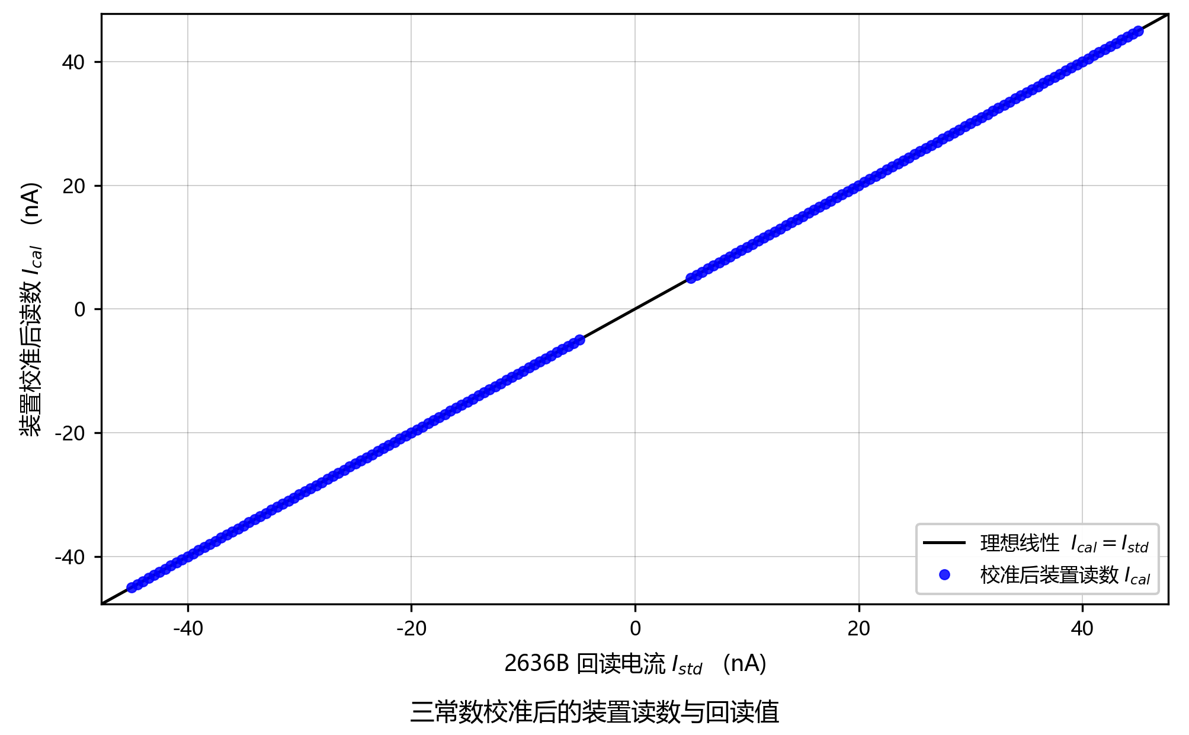
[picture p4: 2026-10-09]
image_paper/fig02_cal.png

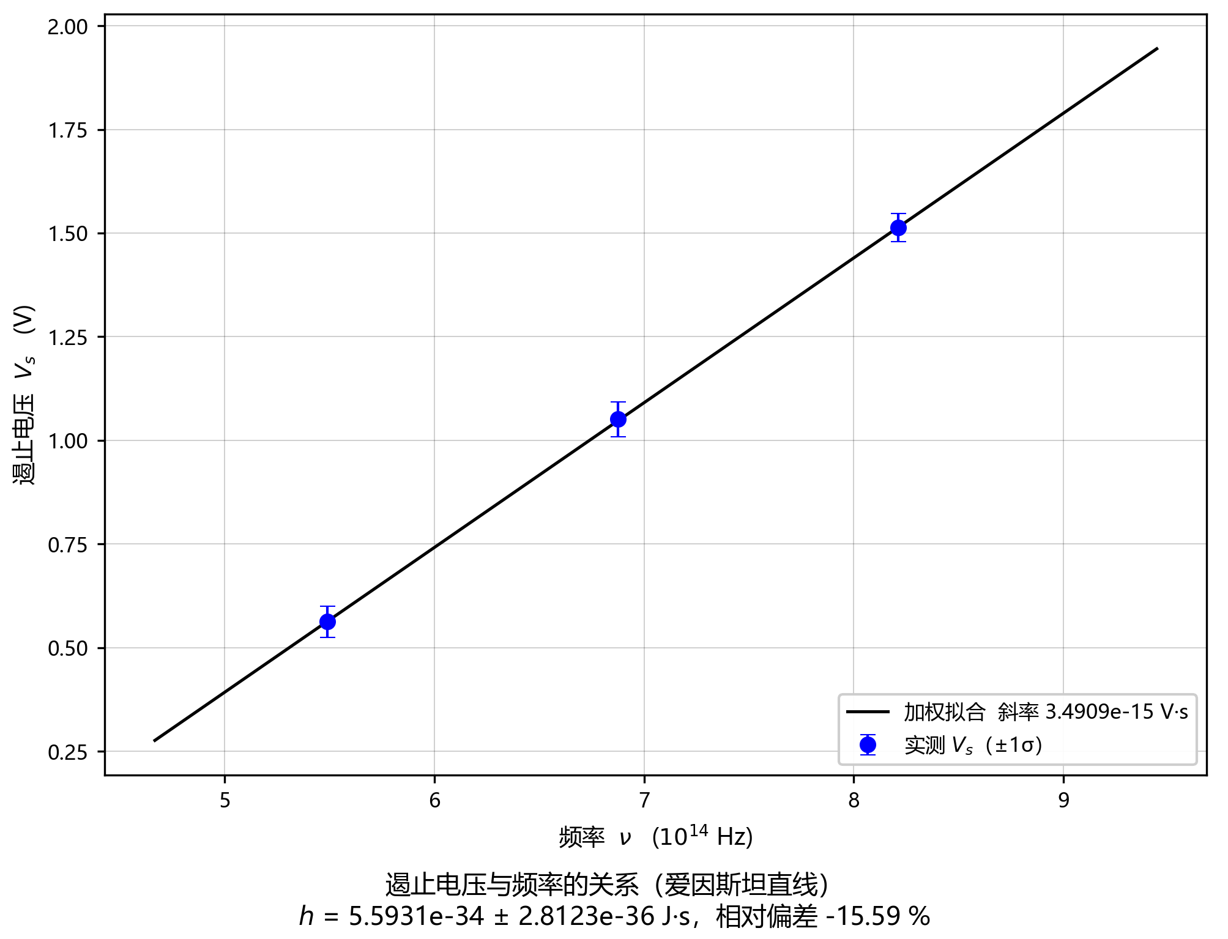
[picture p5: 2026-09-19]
image_paper/fig10_einstein_plot.png

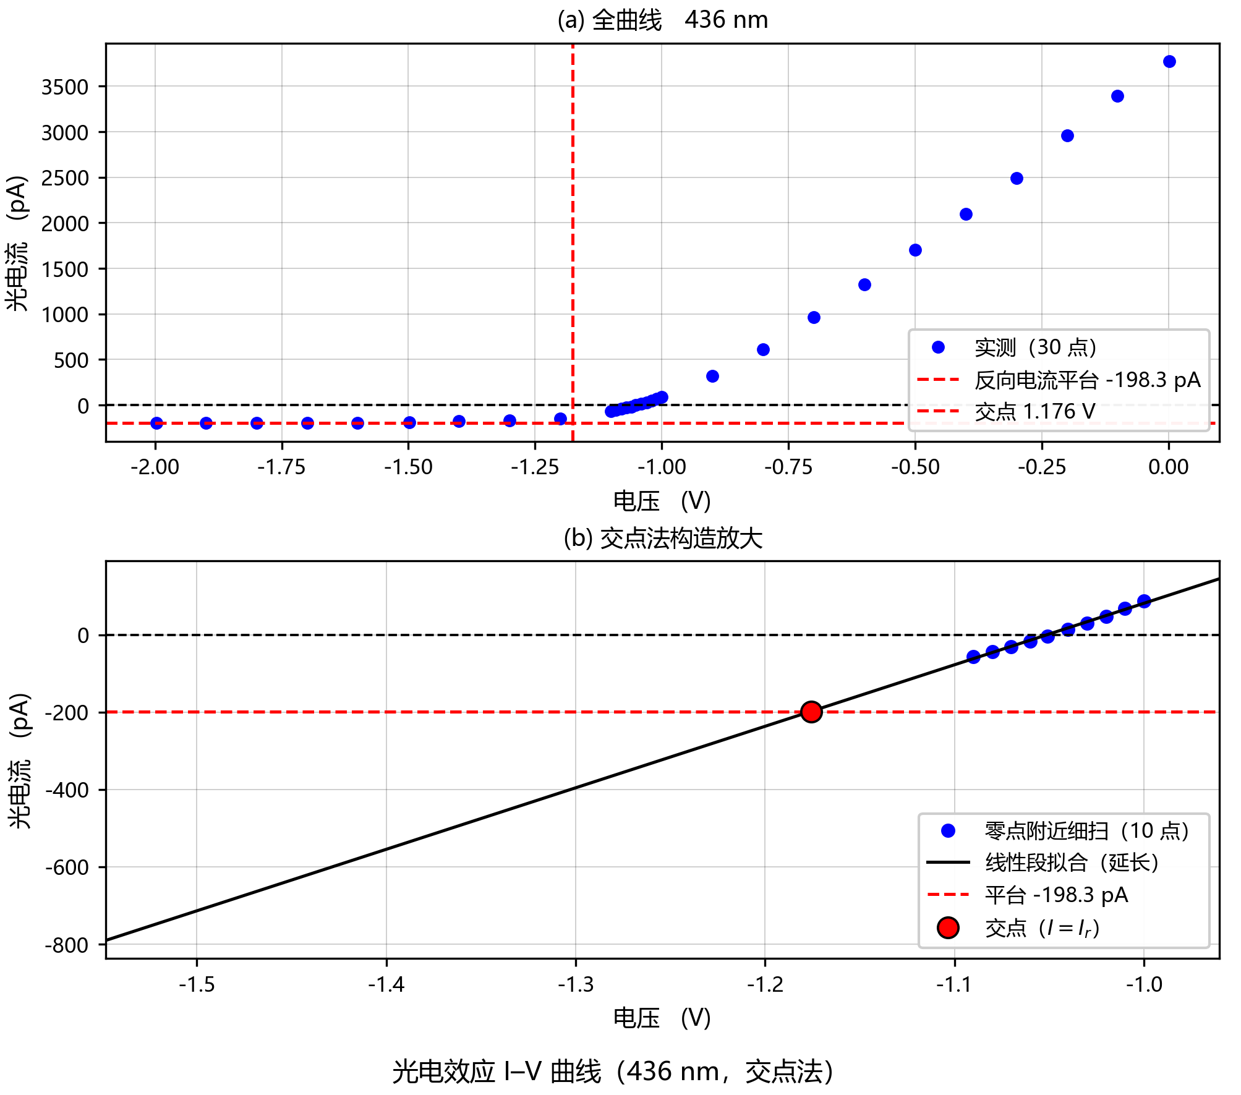
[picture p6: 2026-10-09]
image_paper/fig09_photoelectric_436nm_inter.png

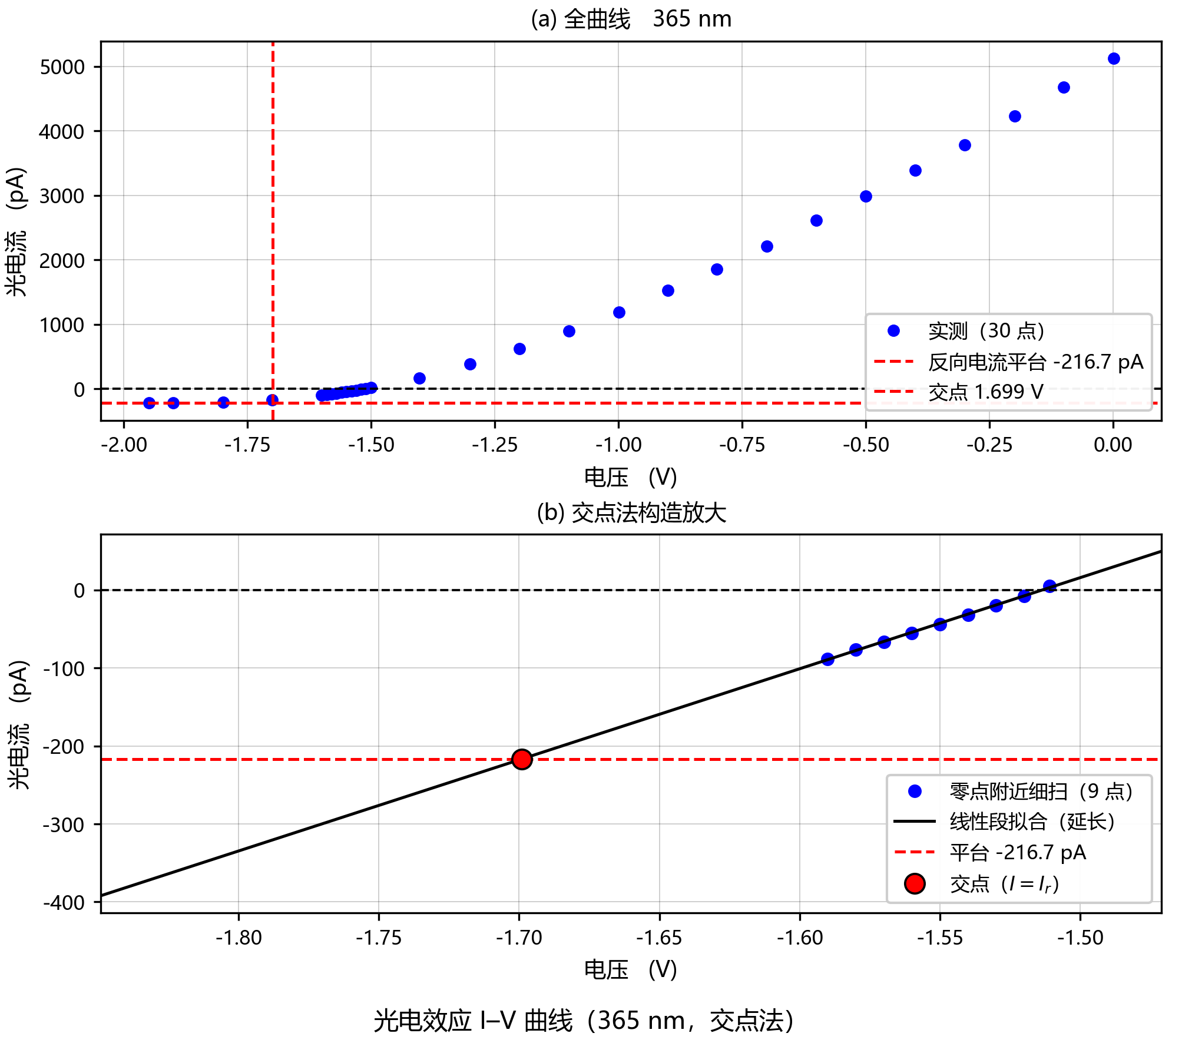
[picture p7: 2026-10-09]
image_paper/fig08_photoelectric_365nm_inter.png

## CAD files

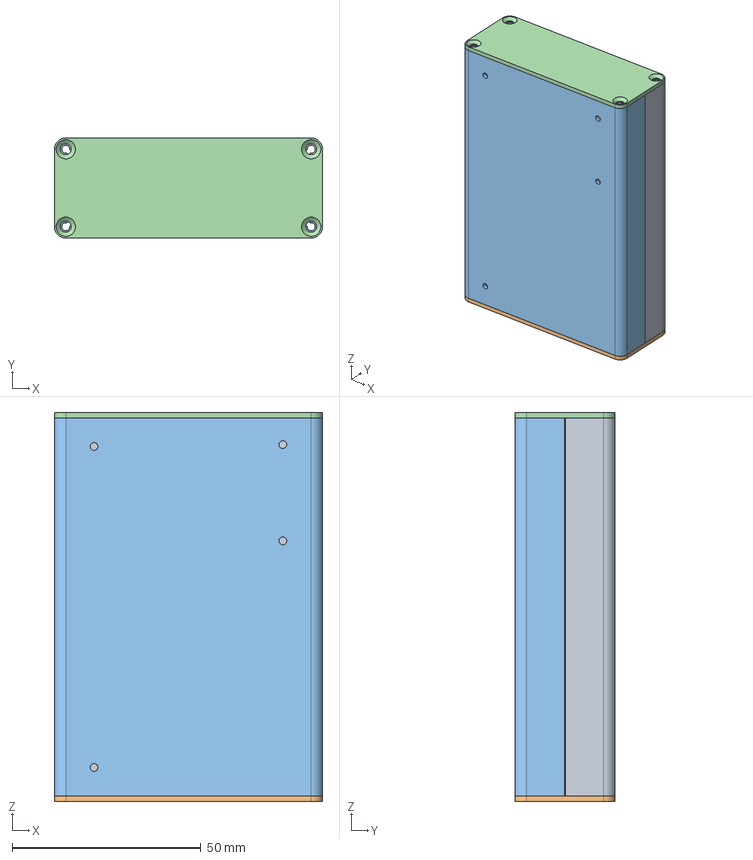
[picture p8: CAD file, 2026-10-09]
hardware/enclosure.stp
71.0 x 26.5 x 103.0 mm

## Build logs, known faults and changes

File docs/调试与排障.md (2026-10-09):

# 调试与排障

> # ⚠️ 这是「某一版特定硬件」的调试记录 —— **不必要参考**
>
> **本项目遇到过的大部分问题，根因是硬件设计错误，不是软件问题。**
> 本文档记录的是**这一版（有缺陷的）硬件**上踩到的坑。
>
> **作者将在开源方案时发布修正后的硬件版本。** 那一版的前端拓扑、器件选型、
> 接线与供电都可能与本文描述**完全不同** —— 届时以新版硬件文档为准，
> 不要把本文当设计依据。
>
> **阅读指引：**
>
> | 节 | 是否可参考 |
> |---|---|
> | 二、已验证的工程结论 · 固件部分 | ✅ **可参考** —— 软件层面的坑，与硬件版本无关 |
> | 六、调试教训 | ✅ **可参考** —— 方法论，与硬件版本无关 |
> | 三、硬件链路 | ⚠️ **仅对本版硬件有效**（含已失效的接线与初始化细节） |
> | 四、待复核 | ⚠️ 仅对本版有意义 |
> | 五、已排除的怀疑方向 | ⚠️ **几乎全是硬件设计错误的产物**，修正版不会重现 |
> | 一、调试手段 | ✅ 大体可参考（通用 SWD/OpenOCD 手段） |

面向**使用**的说明（构建、协议、标定流程）在 [README](../README.md)。

> **另外**：2026-09-12 之前，本文件（及其前身）把一批未经验证的硬件诊断
> 当成既定事实写入，结果大面积出错。现在按验证状态分节，
> **未经复核的不要当结论用**。

---

## 一、调试手段

### 烧录

```bash
openocd.exe -f <...>/scripts/interface/stlink-v2-1.cfg \
            -f <...>/scripts/target/stm32l4x.cfg \
            -c "adapter speed 2000" \
            -c "program <elf> verify reset exit"
```

OpenOCD 在 `C:\Users\40512\STM32Toolchain\openocd\bin\`。
**克隆 ST-Link 必须用 `stlink-v2-1.cfg`**，脚本路径要写全。

串口烧录备选：`scripts/misc/uart_flash.py`（AN3155 Bootloader，需 BOOT0 拉高复位）。

### 读内存 / 看状态机

```bash
arm-none-eabi-nm firmware-v0.elf | grep <符号>   # 查符号地址
# OpenOCD 里:
mdw <地址>                                        # 读 32 位字
```

halt 后读 PC：

| PC 范围 | 含义 |
|---|---|
| `0x0800xxxx` | 在跑固件 |
| `0x1fffxxxx` | 停在系统 bootloader |

### VTref 假警报（克隆 ST-Link）

**克隆 ST-Link 没有真正的 VTref 检测脚**，OpenOCD 报的 `Target voltage`
是内部悬空的垃圾值，永远修不好也不用管。

出现 `Error: target voltage may be too low` 时**先看 SWD 有没有识别核心** ——
只要出现 `Cortex-M4 r0p1 processor detected` + `6 breakpoints, 4 watchpoints`，
就说明芯片有电、链路可靠（同一轮里那个读数会在 0.88/1.03/1.24/1.32V 之间乱跳，
稳定的轨不会这样）。

> **不要因为这句话去推翻已有的诊断。万用表读数为准。**

---

## 二、已验证的工程结论（代码里可查，不是诊断）

### ADC 时钟必须用 SYSCLK

本工程 HAL 版本对 L431 的 PLLSAI1 路径有缺陷（L431 PLLSAI1 无 M 分频器，
HAL 写出非法配置且**不使能 PLL**）→ ADC 无时钟 → 转换永不完成 →
中断内轮询死锁、采样恒 0。

**已改为 `RCC_ADCCLKSOURCE_SYSCLK`（80MHz，在 L431 fADC 上限内）。**
见 `adc.c` 的 `HAL_ADC_MspInit` 注释。

### 中断内不能依赖 `HAL_GetTick`

TIM6 中断优先级 0 高于 SysTick 的 15 → 中断执行期间 SysTick 无法抢占 →
tick 停走 → 任何依赖 tick 的超时轮询变成死循环。

`Adc_ReadRaw()` 与 `ads8866.c` 全部改成**寄存器级轮询 + 循环计数守卫**。

### 守卫的写法（本工程踩过）

```c
guard = 200000U;
while (((REG & FLAG) == 0U) && (guard != 0U)) { guard--; }
if (guard == 0U) { /* 超时 */ }
```

**绝不能写 `guard-- > 0U`** —— 那样最后一次判断会多减一次，下溢成
`0xFFFFFFFF`，后面 `guard == 0U` 的超时判断永远不成立，守卫形同虚设；
转换一旦不完成就是死循环。

### L4 校准函数会关掉 ADC

`HAL_ADCEx_Calibration_Start()` 结束后 ADEN=0，寄存器级读取前需重新使能并等
ADRDY。见 `Adc_Init()`。

### STM32L4 是经典 SPI

只有 `CR1/CR2/SR/DR`，**没有** H7 的新 SPI（`CFG1/CFG2`）。
16 位帧要 `CR1.DFF` 或 `CR2.DS=0xF`。

### ADS8866 用 3 线 CS 模式

CONVST 上升沿时 **DIN 必须为高**，否则芯片进菊花链模式。
因此每次传输都发 `0xFFFF` 维持 DIN 高。

并且：CONVST 拉起之前必须先写过一次 SPI DR（让 DIN 变高），
否则第一次 CONVST 时 DIN 还是低 → 进菊花链 → 读回 0x0000/0xFFFF 之类的
无效码，平白给坏读计数记上一笔假故障。见 `ADS8866_Init()` 的注释。

### 电平移位反相映射

`V_ad = 1.55 − 0.33·V_o`（反相求和器，论文确认）。

阈值码（3.3V / 65536）：`code_lower = 2602`↔V_o=+4.3V，
`code_upper = 58963`↔V_o=−4.3V，`code_zero = 30782`（V_o=0）。

> **这几个阈值码是用标称的 `LEVELSHIFT_GAIN = 0.33` 和 `LEVELSHIFT_V_ADC_ZERO = 1.55`
> 算出来的，两个都没实测过。**
>
> 影响范围有限：式(6) 里 `V_ADC_ZERO` 在端点差里**约掉**，`GAIN` 被吸收进可标定的
> `q` —— 所以**它们不影响测量精度**。真正受影响的只是"实际摆幅到底是不是 ±4.3 V"，
> 而那只决定 bang-bang 的周期长度。
>
> 想验证的话：看 `B` 回传波形的 min/max 是否 ≈ 2602 / 58963。**对不上不影响结果，
> 只是说明摆幅不是设计值。**

### 内置 ADC 的码域（容易搞错）

内置 ADC 是 **12 位**，写进缓冲前做了 `raw << 4` 归一化到 16 位域
（`adc.c`：`adc_last_raw = (uint16_t)((uint32_t)raw << 4);`）。后果：

- **所有码值都是 16 的倍数**，有效分辨率 16 码（不是 1 码）
- **满量程在 16 位域是 65520**（= `4095 << 4`），**不是 65535**
- ADS8866 是真 16 位，满量程才是 65535

所以看到 `65520` 不是异常值，是内置路撞满量程。

---

## 二·补、HSE 晶振（2026-09-12 实测，推翻旧结论）

### 结论：晶振是好的，可以用；但 PLLM 不能取 1

| 配置 | 结果 |
|---|---|
| SYSCLK = MSI（原配置） | 正常 |
| SYSCLK = HSE **直连**（不过 PLL） | 时钟切换成功，但串口读不出 |
| SYSCLK = HSE + PLL，**PLLM = 1**，N = 20 | **INVSTATE HardFault** |
| SYSCLK = HSE + PLL，**PLLM = 2**，N = 40 | **正常工作** |

**晶振本身没问题**：置 `HSEON` 后 `RCC_CR.HSERDY` = 1；示波器实测 7.999989 MHz
（偏差 1.4 ppm）。**旧记录里"板上 8 MHz HSE 不起振、必须用 MSI"是错的。**

**`PLLM = 1` 这个坑值得记**：HSE 8 MHz ÷ 1 = 8 MHz VCO 输入，**在 4–16 MHz
规格内、合规**；查 ST 文档与 erratum 都没找到禁止它的条款（只找到 CubeMX 一个
"生成的代码漏写 PLLM、默认成 8"的旧 bug）。但实测就是崩：

```
CFSR = 0x00020000  (UFSR.INVSTATE —— 指令流被破坏)
HFSR = 0x40000000  (FORCED, 升级为 HardFault)
LR 落在 Measurement_Task 调 MeasurementState_Process 之后
```

换成 **PLLM = 2 / PLLN = 40**（VCO 输入 4 MHz，输出仍是 160 MHz / PLLR=2 → 80 MHz）
就完全正常。

**没有解释，只有实测**。以后 L4 配 HSE 建议直接用 PLLM ≥ 2。

验证方式（不改固件）：
```
mww 0x40021000 0x00010000   # 置 HSEON
mdw 0x40021000              # bit17 HSERDY=1 即起振
mdw 0x40021008              # RCC_CFGR: bits3:2(SWS) = 0b10 表示 SYSCLK 已切 HSE
mdw 0x40021000              # RCC_CR: bit24(PLLON) 确认 PLL 开关状态
```

## 二·补二、CAL_BANG 标定固件从来没工作过（2026-09-12 发现并修复）

TIM6 中断的路由写错了：

```c
#if CAL_MODE == CAL_NONE
    Current_Process();
#else
    CalMode_Tick();     /* 标定固件: 节拍路由到标定逻辑 */
#endif
```

而 `CalMode_Tick()` 里只有 `CAL_ZERO` 的代码，`CAL_BANG` 分支是空的 ——
注释还写着"CAL_BANG: 采样由 Current_Process 完成"，**但那条路根本没被走到**。

后果：电压缓冲永远填不满、`finish_flag` 永远不置位、`CalBang_Report` 永远不执行。
**烧 CAL_BANG 固件后串口一行都不出。**

**这是长期存在的 bug**：`firmware-v0` 与更早的 `prototypes/OLED_SH1106` 里都是同一份
代码，也就是说这个标定固件从来没有出过数据。

修法 —— 只有 CAL_ZERO 需要走自己的逐拍累加：

```c
#if CAL_MODE == CAL_ZERO
    CalMode_Tick();
#else
    Current_Process();
#endif
```

修好后实测（无输入，参考电流交替）：

```
CAL BANG: m=3121 n=3129 VPP=+8.75V MIN=2080 MAX=59440 I=-0.026nA
```

逐项核对全部符合设计：`m+n = 6250`、VPP 8.75V（设计 8.6V + 过冲）、
MIN/MAX 比阈值高/低约 515 码（正好是一拍的路程：500V/s × 160µs = 525 码）。

## 二·补三、参考电流的共模偏移以 1:1 进入读数（2026-09-12）

把补偿项按共模/差模拆开（令 `I₊ = I + d`，`I₋ = −I + d`）：

```
comp = (m·I₊ + n·I₋)/N = [(m−n)·I + (m+n)·d] / N
                           └─ 差模, 8.04 pA/计数   └─ 共模, 系数 (m+n)/N ≈ 1
```

**共模偏移 `d` 无衰减地进入每个读数。** 实测（短接积分节点 + 万用表量参考电阻压降，
R = 99.48 MΩ）：

```
V+ = 4.99703 V   V- = -4.99938 V     对称性差 0.047%
I₊ = +50.232 nA  I₋ = -50.255 nA
d  = (I₊ + I₋)/2 = -11.5 pA          <-- 直接加到每个读数上
```

参考电流只差 0.047%，但补偿项从 −56 变到 −68 pA，而模式一总读数才 20 pA ——
**放大了一百多倍**（因为补偿项是两个大数相减）。

**这是本架构的固有弱点**：I₊/I₋ 的温漂会 1:1 传进读数，是报告 4.7 节
不确定度预算里权重最大的一项；标定时**必须分别测两个极性**。

## 二·补四、分辨力实测（2026-09-12）

用 09-11 实采数据 + 二阶差分/MAD 估单点噪声：

| | 单点噪声 |
|---|---|
| 内置 ADC | 48.4 码 |
| ADS8866 | 49.0 码 |

**两种 ADC 噪声一样** —— 说明噪声来自模拟前端（积分器 + 电平移位），不在 ADC 里。
**换 ADS8866 对分辨力没有帮助。**

| 模式 | 单次分辨力 |
|---|---|
| 模式一（1 秒窗口，端点单点采样） | **~1.0 pA** |
| 小电流模式（3 秒纯积分，端点 8 点平均） | **~0.13 pA** |

计数那个 8.04 pA 的台阶**不是瓶颈**：一次计数变化对应端点差 523 码，
而端点噪声只有 48 码，插值毫无问题。**瓶颈是端点用单点采样。**

## 二·补五、模式一的 `T=` 一直报 0ms（2026-09-12 发现并修复）

`measurement_state.c` 里 `measurement_ticks` **只在转入小电流模式那个分支被
赋值**，模式一那条路径从头到尾没碰过它，于是 `MeasurementState_GetTicks()`
恒返回初值 0 —— 每个模式一结果行都是 `T=0ms`。

后果不是"少个字段"，是**报告里 `I = C·ΔV/T` 的 T 直接错**（README 白纸黑字
写着模式一固定 1000ms，实际报 0）。修法是在模式一取结果处显式赋值：

```c
measurement_ticks = Current_GetSampleCount();   /* 恒为整窗 6250 拍 */
```

**教训**：这种"某个变量只在一条分支里被写"的 bug，编译器不会说话，
测试不跑那条路径也看不见。凡是结果行里出现的量，都要问一句
"它在**这条**分支上被赋过值吗"。

## 二·补六、`EN=0` 不是"0 A"，是 Hi-Z（2026-09-12 发现，**待实测 τ**）

### 现象

ADG1219 是单刀双掷：`EN=1` 时 A/B 二选一（+5V 或 −5V）；`EN=0` 时**两个都断**，
100 MΩ 那一端**浮空**，不是被拉到 0 V。

示波器实测：`+5 ↔ −5` 切换是正常方波；而 `0 ↔ +5` 时**上升沿正常、下降沿指数衰减**。

**不对称是必然的**：接通时开关的通态电阻很小、瞬间把节点强拉到 ±5V；断开后没有任何
主动驱动，只有 `R=100MΩ` 把那个节点的寄生电容 `C_p` 慢慢泄放到虚地：

```
i(t) = (V_n / R) · e^(−t/τ)        τ = R · C_p
总电荷 Q = C_p × V_n
```

**所以程序绝不能把 `EN=0` 当成"精确的 0 A 参考"。**

### 哪些地方受影响

四处**"复位后做纯积分"**——它们全都靠 `EN=0` 当 0 A：

| 位置 | 用途 |
|---|---|
| `SmallI_Start`（小电流模式） | 复位后纯积分 1 pA ~ 1 nA |
| `Noise_Start`（底噪） | 复位后纯积分 |
| `CalMode_Start`（CAL_ZERO） | 复位后纯积分 |
| `HardIntegral_Start`（模式二上积相，仅 `firmware-v0`） | 复位后纯积分 |

**模式一不受影响**——它在窗口里只在 ±I_ref 之间切换，**从不进 `EN=0`**。

### 量级

`τ = 100MΩ × C_p`，`Q = C_p × 5V`，而 1 码 = 1.526e−14 C：

| `C_p` | `τ` | 总电荷 | 折合码 |
|---|---|---|---|
| 0.1 pF | 10 µs | 0.5 pC | 33 码 |
| 1 pF | 100 µs | 5 pC | 328 码 |
| **10 pF** | **1 ms** | **50 pC** | **3277 码** |
| 100 pF | 10 ms | 500 pC | 32770 码 |

**`C_p` 现在没人知道**——而它决定后面所有选择。

> ⚠️ **示波器量不准**：探头自身就有 10 pF 量级，会盖过板上的 `C_p`、把 τ 放大十几倍。
> 必须用别的办法。

### 怎么量 `C_p` / τ（下次上板）

用本仪器自己——它的 ADC 就是干这个的：

```
1. 拉回到接近 0V（参考接通）
2. ADG_Disable() 断开参考        <- 这一瞬注入 C_p × 5V
3. 立刻连续采样（每 160µs 一点），采几百点
4. 那段电压是「台阶 + 指数衰减」-> 拟合出 τ
   C_p = τ / 100MΩ,  总电荷 = C_p × 5V
```

判据：**τ 与 160 µs 的比较**

- `τ ≪ 160 µs`（`C_p` ≲ 0.1 pF）→ **无事**，四处纯积分模式都不用动
- `τ` 是 ms 量级 → 必须处理（见下）

### 处理方案（等 τ 出来再定）

| | 做法 | 代价 |
|---|---|---|
| **软件** | 拉回后等 `> 5τ` 再取起点（把 `SI_SETTLE_TICKS` 按实测 τ 定） | 只治标；大电流时 T 短、τ 相对更长 |
| **硬件** | 让 `EN=0` 接**真正的 0V**（换三掷开关，或加一路开关到地） | 要改板。**唯一能让"0V 参考"变成真的办法**，且一次解决四处 |

### 连带影响：`q` 的标定方法必须换

原定的 `q` 测法是"**参考断开** + 灌已知电流 + 积分"——**"参考断开"就是 `EN=0`**，
暂态会直接混进 `Δc`：

```
暂态 50 pC（C_p=10pF） -> 3277 码
信号 400 pC（50nA 积 8ms） -> 26212 码
误差 = 12.5%          <- 会整条传播到所有结果
```

**改用 `I₊` 自标**：把 ADG **固定在一个极性、关掉 bang-bang**，积 M 拍：

```
q = I₊ · (M · 160µs) / Δc
```

全程不进 `EN=0`，完全避开暂态；而且 `I₊` 走现成的参考通路，不引入新节点新电容。

**这需要加一个"固定极性积分"的固件模式（现在没有）。** 同一个模式还能顺便量 τ 和
参考电流的对称性。（`I₊` 自标的 `q` 只能把仪器做成**比值仪器**——精度锚在 `R` 上，
见「参考电流的共模偏移」一节）

### 附带结论：待测电流什么时候接

```
S 指令 -> 拉回相（约 10ms，最坏 400ms）-> 窗口 1.000s -> 出结果
```

**待测电流必须在整个拉回相期间就接好**——因为拉回相本身就受它影响
（净电流 = I_ref − I_x，决定拉回多快）。中途接入会让起点不可预期。

## 三、硬件链路（⚠️ 仅对本版硬件有效）

> 下面这些接线与器件细节是**这一版硬件**的实际情况。作者开源时会发布
> 修正后的硬件版本，届时以新版为准。

### OLED

- 屏幕 HS13L01（汉昇，128×64，SH1106，带字库芯片）
- 接线：**PB13=SCL、PB15=SDA、PB14=DC、PB12=CS1**；
  SPI2 模式 0、2.86MHz（规格上限 3.3MHz）。FS0 悬空、CS2 接 3V3 禁用字库
- **初始化序列必须含电荷泵使能**：`0xAD,0x8B`、`0x33`(VPP 9V)、`0xD9,0x1F`、
  `0xDB,0x40`。早期记录说原 SH1106-master 驱动缺这几条是屏幕不亮的根因

### 供电

台式电源 3.3V 或 ST-Link 供电都可行，两条路都稳定。

### 时钟

固件用 **MSI 内部时钟**：MSI 48MHz → PLL(M=6) → SYSCLK 80MHz
（`main.c` 的 `SystemClock_Config`）。

**注意**：这不能推断 HSE 晶振是坏的 —— 那正是下面被排除的一条。

---

## 四、待复核 / 未验证

### 4.0 上板验证清单（2026-09-12 累积，全部从未在硬件上跑过）

按"能一次跑完"的顺序排。**前两项是新增的物理测量，后六项是回归验证。**

| # | 验什么 | 判据 |
|---|---|---|
| **1** | **`C_p` / τ**（见二·补六） | 拉回后断开参考、立刻连续采样几百点，拟合指数 → `τ`。**与 160µs 比**：远小则无事，ms 量级则四处纯积分模式都要处理 |
| **2** | **`q` 用 `I₊` 自标**（需要"固定极性积分"模式，尚未实现） | `q` 应落在标称 `1.5259e-14 C/码` 的 ±5% 内（标称由 `100pF × 3.3V /(65536 × 0.33)` 三个猜的值相乘得出） |
| **3** | **拉回相**（目标已改成 0V） | `B` 回传波形**首点应 ≈ `code_zero`(30782)**，不再是 65520；开头饱和前缀为 0 |
| **4** | **拉回相搬进 ISR + 分母 `m+n`** | 结果行 `T=` 应为 **1000ms 整**；`RAW` 段的 `m+n` 应 = **6250**；连测两次同一电流应逐位相同 |
| **5** | **`RAW` 段** | `RAW m=.. n=.. INT1=.. INT2=.. EXT1=.. EXT2=..` 六个字段齐全；`INT1`/`EXT1` 是拉回最后一拍（V_01），不是 `voltage_buf[0]` |
| **6** | **`T=0ms` 修复** | 由 #4 一并验（旧行为是每个模式一结果行都报 `T=0ms`） |
| **7** | **坏读判据** | 输入撞轨时 `E` 报的 `ERR` **不应暴增**（旧行为：底噪那一轮从 37 虚涨到 312537） |
| **8** | **`Q` 指令 / 物理常数走 Flash** | `Q` 查询回 `CAL Q 15259,50232,-50255` 量级；`Q<...>` 写入回 `CAL Q SET ...`；**掉电重上电后仍在**（证明写进 Flash 了）；`Z` **不应**清掉它们 |

**另外 `firmware-v0` 的 HSE 时钟改了但从未烧录过**，也要跑一次。

> 建议顺序：先跑 #1（τ 决定后面怎么走），再一口气跑 #3~#8。

### HSE 晶振电路

不改固件就能验：

```
mww 0x40021000 0x00010000     # RCC_CR: 置 HSEON (bit16)
mdw 0x40021000                # 读回: bit17(HSERDY)=1 即起振成功
```

复位即恢复，不影响 Flash 内容。起振则可以考虑把系统时钟换成 HSE
（比 MSI 准，对外部 ADC 时序和串口都更稳）。

### 测量数值全部待复测

`I_ref`、绝对增益、积分电容值、两路 ADC 一致性 —— 2026-09-11 记录过一批
数值，但未经独立复验。**当前策略：全部用 `current.h` 里的标称值计算**，
标定留到后续详细测试之后。标定值的落点就是 `current.h` 的宏，
**没有独立的拟合头文件**。

### 窗口计数与 ADG 相位

旧记录称 `m_count`/`n_count` 的窗口复位与 ADG 切换不同步、窗口长度 6250
不是周期（约 236 点）的整数倍 → 窗口刚重置时占空比读数严重失真。

**已解决（2026-09-12 重构）**：拉回相搬进了 TIM6 中断，窗口两端（`V_01` 与最后
一个窗口采样）都是 ISR 采样、采样偏移相同，计数覆盖的正好是它们之间的 6250 个
间隔。于是 `n_total = m+n = 6250`（**不用减一**）、窗口时长 = 6250×160µs =
**1.000 s 整**，论文的 `(m+n)` 形式精确成立。

**为什么"在主循环里拉回"不行**：那样 `V_01` 到采样点 0 的间隔是
`160µs + 读一次 ADC 的耗时 + 启动 TIM6 的代码延时`，比整一拍多出后两项。
残差公式：

```
误差 = I₊ · (C_ISR + δ) / 窗口时长
     = I₊ · (读一次的耗时 + 启动延时) / 1s
     ≈ 50nA × 12µs / 1s ≈ 0.6 pA   （恒定，但依赖编译结果，说不清来源）
```

**注意**：旧实现（在主循环里拉回、计数减一）**也是精确的** —— 它只要保证
"减的那一拍"减在开窗极性对应的计数器上。两者都对，区别只是新实现让分母直接
等于 `m+n`，报告里和论文对得上。

> **踩过的坑**：中途曾让开窗极性跟着拉回方向走（从上面拉就用 NEG、从下面拉就用
> POS），却仍固定减 `n_count`。那样等于**减错极性**，误差是
> `(I₊−I₋)/(N−1) = 100.5nA/6249 ≈ 16.1 pA`，而且**随开窗极性翻符号** ——
> 是噪声不是偏置，`a/b` 拟合吸收不了。比"用哪种分母"严重得多。

### 拉回相

为解决「窗口开头端点撞轨」（实测开头 38 个样本压在满量程）而加，
**尚未在硬件上确认有效**。验收判据：`B` 回传的波形**首点应 ≈ `code_zero`(30782)**
（拉到 0V 再开窗），不再是 65520；开头饱和前缀应为 0。

> 目标点位的选择：**拉到 0V 而不是某个阈值**。拉到边界是赌电流符号 ——
> 赌错那侧余量为 0、第一拍就撞轨；0V 则两个方向各留 4.3V，且第一个相位是
> 正常长度（停在阈值上会退化成 1 拍的相位）。

### 模式二只覆盖一个极性

上积相等待 `raw <= code_target`（原始码下降 = V_int 上升 = 与 I_POS **反号**的
电流），**正的小电流永远不触发** → 10 s → `HARD_TIMEOUT`。

---

## 五、已排除的怀疑方向（⚠️ 几乎全是硬件设计错误的产物）

> **这一节的内容对修正版硬件基本没有参考价值。**
> 它们是在这一版有缺陷的硬件上排查时走过的弯路，根因多为硬件设计错误。
> 保留在此只为：如果有人恰好拿到这版硬件，不必再走一遍。

以下方向**经 2026-09-12 复核判定不成立**：

| 已排除 | 备注 |
|---|---|
| ADS8866 会成串读到 0xFFFF、怀疑手工飞的 SPI 线信号完整性 | 实采数据里斜坡中段零坏读 |
| PB4 按键硬件故障、恒读低 | 代码里 `BUTTON_DISABLED` 的依据只是当时的判断 |
| 板上 8MHz HSE 晶振不起振 | 未验证；固件用 MSI 不能推出 HSE 坏 |
| BOOT0 按键焊点不良、串口烧录需飞线 | 未验证 |
| 板载 CH340 的 USB-C 线易松脱 | 未验证 |
| 模拟部分电源未接、ADC 读数为运放悬空电平 | 与摆幅 ±4.38V 正常的实采矛盾 |
| ADS8866 的 AINP/AINN 在板上接反 | 实测 `ext ≈ 1.0005×int + 7.3`，同号且几乎相等，无反相 |
| 改 `ads8866.c` 的 `USE_MCU_ADC` 可切 16 位 | 该宏在当前固件里不存在 |
| 积分器钉轨根因是积分器硬件损坏 | 未经复验 |

---

## 六、调试教训（踩过的坑）

- **日志里的下标和环形缓冲对不上时，先怀疑计数器语义。**
  `ext_err_total` 从开机累加不清零，而环形缓冲每窗口重写 —— 日志里的下标在
  缓冲区里读到的是本窗口（更晚）的数据，两者本来就不该对应。
  **不要照这个去反汇编 `Current_Process`，纯属浪费时间。**
- **测出的"系数不对"先怀疑自己用的元件参数，再怀疑硬件。**
  早期算出「I_ref 只有 14.5nA、比标称小 3.44 倍」，根因是电容用了 30pF
  而实际是 100pF（3.44 × 30 ≈ 103 pF）。
- **不要拿早期会话写下的硬件诊断当事实引用。** 那些结论大多来自单一观察加
  推理，没有独立验证。引用时标注来源与日期，并优先用当前代码或实采数据复核。

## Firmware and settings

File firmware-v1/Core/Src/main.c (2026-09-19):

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
/* Includes ------------------------------------------------------------------*/
#include "main.h"
#include "adc.h"
#include "spi.h"
#include "tim.h"
#include "gpio.h"

/* USER CODE BEGIN Includes */
#include "sh1106.h"
#include "font7x10.h"
#include "uart.h"
#include "adg4530.h"
#include "ads8866.h"
#include "button.h"
#include "current.h"
#include "measurement_state.h"
#include "cal_coef.h"
#include "cal_mode.h"
#include <stdio.h>
/* USER CODE END Includes */


/* USER CODE BEGIN PV */
/* PB4 按键硬件故障 (恒读低), 全部按键功能关闭 (用户决定):
 * 控制一律走串口/HTML 控制台; PB4 修好后删掉此宏即可恢复 */
#define BUTTON_DISABLED
static uint8_t has_result = 0;
/* 1 = HSE 8MHz 晶振; 0 = MSI 内部 RC (实测 HSE 起振正常, 见 docs) */
#ifndef CLOCK_USE_HSE
#define CLOCK_USE_HSE 1
#endif

const char *clock_source_name = "?";   /* 实际用上的时钟源, READY 行报出来 */
/* USER CODE END PV */

void SystemClock_Config(void);
/* USER CODE BEGIN PFP */
static void Measurement_Task(void);
static void OLED_DrawScreen(const char *value, const char *unit, const char *mode);
static void FormatCurrentNA(float current, char *buf);
static void UART_SendResultLine(float cur_int, float cur_ext, uint8_t mode,
                                uint8_t timeout);
static void UART_SendResultQuery(void);
static void UART_DumpBuffer(const char *tag, uint16_t (*get)(uint32_t), uint32_t count);
static void UART_DumpWaveform(void);
static void UART_DumpExtWaveform(void);
static void UART_SendExtDiag(void);
/* USER CODE END PFP */

/* USER CODE BEGIN 0 */
/* ============================================================
 * 显示: 数值行 + 单位 + 模式状态行 (SH1106-master 驱动, 7x10 字体)
 * ============================================================ */
static void OLED_DrawScreen(const char *value, const char *unit, const char *mode)
{
    uint8_t x;

    SH1106_Fill(0x00);
    x = (uint8_t)LCD_PutStr(0, 6, value, fnt7x10);
    x = (uint8_t)LCD_PutStr(x + 3, 6, unit, fnt7x10);
    LCD_PutStr(0, 28, mode, fnt7x10);
    SH1106_Flush();
}

/* 电流 -> nA 文本。**量化到 0.01 pA** (nA 保留 5 位小数)。
 *
 * 2026-09-17 由 3 位小数 (= 整 pA) 改成 5 位。依据是噪声, 不是想要更多数字:
 * 50 s 窗下单次噪声约 **0.045 pA** (σ_I·τ≈0.8 pC 那条不变量给 0.016 pA),
 * 而旧的 1 pA 步长比它粗 20 倍 —— 低电流段(光电流那批 ~10 pA)的真实结构
 * 被显示分辨率吃掉了。0.01 pA 是噪声的 1/4, 位数站得住; 再细就是假精度。
 *
 * 实现: pA 值乘 100 变成"以 0.01 pA 为单位"的整数, 再印 5 位小数。
 * ⚠️ 上限因此不能再用 9.0e18 —— 乘 100 会溢出 int64, 收到 9.0e16。
 *    这个上限纯属溢出保险丝 (物理量程只有 ±50 nA), 不参与任何判据。
 * ⚠️ 值字符串最长 1+17+1+5 = 24 字节 + NUL, 调用处的缓冲已相应加大
 *    (UART_SendResultLine 的 vi/vx/vc 与 line, UART_SendResultQuery 的 v)。 */
static void FormatCurrentNA(float current, char *buf)
{
    double v = (double)current * 1e12;
    if (v > 9.0e16) v = 9.0e16;
    if (v < -9.0e16) v = -9.0e16;
    UART_FormatScaled((int64_t)(v * 100.0), 5, buf);
}

/* 结果行: 两个 ADC 的结果都报, 校准生效且非超时时再追加校准值。
 *
 *   I=<内置> X=<外部> MODE=<n> T=<ms> [TIMEOUT] [CAL=<校准后>]
 *   MODE=1 再追加 RAW m=.. n=.. INT1=.. INT2=.. EXT1=.. EXT2=..
 *
 * I= 保持与原固件兼容 (上位机的解析正则不锚定行尾); X= 是 ADS8866 的结果,
 * 物理实验表征以它为准; CAL= 由 X= 经分段校准模型算出, 报告要的是它。
 * 超时时数值无意义, 不出 CAL=。
 *
 * RAW 段是离线拟合要用的原始量: m/n = POS/NEG 周期数, INT1/INT2 与 EXT1/EXT2
 * = 窗口首尾两个端点的原始码 (内置那路 / ADS8866 那路)。INT1/EXT1 是拉回相最后
 * 一拍的采样 (V_01), 不是 voltage_buf[0] —— 式(6) 用的端点就是它。只报电流值的话这些量
 * 就丢了 —— 而 (m+n) 与 (m+n-1) 两种分母之争、以及分段系数 a/b 的拟合,
 * 都得从**同一次测量**的原始量出发, 不然只能靠反推。报告的表 4-9~4-14 也用得上。
 *
 * 两种窗口 (MODE=1 的 1s / MODE=2 的长窗) 都出这一段 —— 它们是同一条测量
 * 逻辑, 只是窗口长度不同 (2026-09-13 重构前, MODE=2 是另一套不算 m/n 的模式)
 * 两段平均, 原始量是另一套 (结果行的 T= 已经给了它的实际积分拍数)。 */
static void UART_SendResultLine(float cur_int, float cur_ext, uint8_t mode,
                                uint8_t timeout)
{
    char vi[32], vx[32], vc[32];
    /* 最坏情况: 三个值各占满 32 字节 -> 2+32+6+32+8+1+5+32+2 = 120;
     * 再加 RAW 段 (最长约 60 字节) 与结尾 NUL。256 留足余量, snprintf 兜底。
     * (值改 5 位小数后单值最长 1+17+1+5=24 字节+NUL, 原来的 24 会截断) */
    char line[256];
    char raw[80] = "";

    FormatCurrentNA(cur_int, vi);
    FormatCurrentNA(cur_ext, vx);

    /* MODE=1 (1s 窗口) 与 MODE=2 (长窗口) 是**同一条测量逻辑**, 都出 RAW 段。
     * 2026-09-13 重构前这里是 `mode == 1U` —— 那时 MODE=2 是另一套不算 m/n 的模式;
     * 现在留着会把长窗口的 RAW 整段跳掉。 */
    if ((mode == 1U) || (mode == 2U))
    {
        uint32_t npt = Current_GetSampleCount();

        if (npt > 0U)                /* 没采到样就不出, 免得报一堆 0 */
        {
            /* 端点必须用 Current_GetLastCode() 而不是缓冲末点 ——
             * 长窗口的缓冲是**抽点**存的 (10 拍存 1 点), 末点离真正的窗口末拍差
             * 9 拍。在锯齿波上那 9 拍 (1.4ms) 能差好几千码, 拿它复算结果会对不上。 */
            snprintf(raw, sizeof(raw),
                     " RAW m=%lu n=%lu INT1=%u INT2=%u EXT1=%u EXT2=%u",
                     (unsigned long)Current_GetMCount(),
                     (unsigned long)Current_GetNCount(),
                     (unsigned)Current_GetFirstCode(),
                     (unsigned)Current_GetLastCode(),
                     (unsigned)Current_GetFirstCodeExt(),
                     (unsigned)Current_GetLastCodeExt());
        }
    }

    if ((timeout == 0U) && Cal_IsValid())
    {
        FormatCurrentNA(Cal_Apply(cur_ext), vc);
        snprintf(line, sizeof(line),
                 "I=%s nA X=%s nA MODE=%u T=%lums CAL=%s%s\r\n",
                 vi, vx, mode,
                 (unsigned long)(MeasurementState_GetTicks() * 160U / 1000U),
                 vc, raw);
    }
    else
    {
        snprintf(line, sizeof(line),
                 "I=%s nA X=%s nA MODE=%u T=%lums%s%s\r\n",
                 vi, vx, mode,
                 (unsigned long)(MeasurementState_GetTicks() * 160U / 1000U),
                 (timeout != 0U) ? " TIMEOUT" : "", raw);
    }
    UART_SendString(line);
}

/* D 指令: 查询最近结果 */
static void UART_SendResultQuery(void)
{
    char v[32];
    char line[96];

    if (!has_result)
    {
        UART_SendString("RESULT NONE\r\n");
        return;
    }

    FormatCurrentNA(MeasurementState_GetResult(), v);
    sprintf(line, "RESULT I=%s nA MODE=%u%s\r\n", v, MeasurementState_ResultIsLongW() ? 2U : 1U, (MeasurementState_ResultIsTimeout() != 0U) ? " TIMEOUT" : "");
    UART_SendString(line);
}

/* 波形回传公共实现 (B / X 共用)
 * 格式: "<tag> <count>\r\n" + count*2 字节小端 u16 + 2 字节校验和(样本和) */
static void UART_DumpBuffer(const char *tag,
                            uint16_t (*get)(uint32_t),
                            uint32_t count)
{
    char header[32];
    uint16_t sum = 0;
    uint32_t i;
    static uint8_t chunk[512];

    sprintf(header, "%s %lu\r\n", tag, (unsigned long)count);
    UART_SendString(header);

    for (i = 0; i < count; i++)
    {
        uint16_t s = get(i);
        chunk[(i % 256) * 2]     = (uint8_t)(s & 0xFF);
        chunk[(i % 256) * 2 + 1] = (uint8_t)(s >> 8);
        sum += s;
        if ((i % 256) == 255 || i + 1 == count)
        {
            UART_SendBinary(chunk, (uint16_t)(((i % 256) + 1) * 2));
        }
    }
    UART_SendBinary((uint8_t *)&sum, 2);
}

/* B 指令: 回传最近完整窗口的内置 ADC (控制通路) 波形 */
static void UART_DumpWaveform(void)
{
    UART_DumpBuffer("WAVE", Current_GetSample, Current_GetSampleCount());
}

/* X 指令: 回传同一窗口的 ADS8866 外部 16 位波形 (格式与 B 完全一致,
 * 只是头字为 WAVEX。两路同索引, 可直接逐点叠图对照) */
static void UART_DumpExtWaveform(void)
{
    UART_DumpBuffer("WAVEX", Current_GetExtSample, Current_GetSampleCount());
}

/* E 指令: 观测通路健康度一行 (免去 12.5KB 回传就能判断好坏)
 * ERR = 坏读数 (0x0000 转换未完成 / 0xFFFF DOUT 常高);
 * TXE/RXNE/BSY = SPI 寄存器级守卫超时次数, 正常应恒为 0;
 * PRE = 模式一拉回相守卫超时次数, 正常恒为 0 (超量程的唯一直接证词) */
static void UART_SendExtDiag(void)
{
    char line[128];

    sprintf(line, "EXT N=%lu ERR=%lu TXE=%lu RXNE=%lu BSY=%lu PRE=%lu "
                  "TINT=%luns TEXT=%luns FFFF=%lu F0=%lu FL=%lu\r\n",
            (unsigned long)Current_GetSampleCount(),
            (unsigned long)Current_GetExtBadRead(),
            (unsigned long)ads_spi_txe_timeout,
            (unsigned long)ads_spi_rxne_timeout,
            (unsigned long)ads_spi_bsy_timeout,
            (unsigned long)precond_timeout,
            (unsigned long)t_int_ns,        /* 时序实测: 内置路单次耗时 */
            (unsigned long)t_ext_ns,        /*           外部路单次耗时 */
            (unsigned long)ext_ffff_cnt,    /* 外部路 0xFFFF 总次数 */
            (unsigned long)ext_ffff_early,  /* 其中落在窗口前 10 拍内 */
            (unsigned long)ext_ffff_late);  /* 其余 */
    UART_SendString(line);
}
/* USER CODE END 0 */

/**
  * @brief  The application entry point.
  * @retval int
  */
int main(void)
{

  /* MCU Configuration--------------------------------------------------------*/

  /* Reset of all peripherals, Initializes the Flash interface and the Systick. */
  HAL_Init();

  /* Configure the system clock */
  SystemClock_Config();

  /* Initialize all configured peripherals */
  MX_GPIO_Init();
  MX_ADC1_Init();
  MX_TIM6_Init();
  MX_USART1_UART_Init();
  MX_SPI2_Init();
  /* USER CODE BEGIN 2 */
  /* ---- DWT 周期计数器: 必须在这里启用 ----
   * 中断里的微秒级忙等 (`DelayUs` / `DWT_DelayUs`) 全靠它。**不能依赖
   * "第一个调用者顺手打开"** —— 2026-09-15 实测踩到:
   *   current.c 的 DelayUs() **裸读** DWT->CYCCNT, 而启用 DWT 的那 4 行在
   *   ads8866.c 的 DWT_DelayUs() 里, 调用顺序上排在 DelayUs **之后**
   *   (USE_INTERNAL_ADC=0 时 ReadBoth 先 DelayUs(EXT_PREDELAY_US) 再读外部)。
   *   -> CYCCNTENA 一直是 0 -> DWT->CYCCNT 恒为 0 -> (0-0)<640 永真
   *   -> **死循环在 TIM6 中断里**, 主循环与串口全停, 连 E 都不应答。
   *   SWD 实测: pc 停在 DelayUs (current.c:69), 状态 Handler External
   *   Interrupt(54)=TIM6; DWT_CTRL=0x40000000 (bit0=0), CYCCNT 连读两次皆 0。
   * 另外: TRCENA 之前是**调试器 attach 时顺手置上的**, 断开调试器就没了 ——
   *       这种"靠调试器帮忙"的隐式依赖必须去掉。 */
  CoreDebug->DEMCR |= CoreDebug_DEMCR_TRCENA_Msk;
  DWT->CYCCNT = 0;
  DWT->CTRL |= DWT_CTRL_CYCCNTENA_Msk;

  ADG_Disable();                 /* 空闲: 关断参考电流 (安全最高优先级) */
  SH1106_Init();
  Adc_Init();                    /* 控制通路: 内置 ADC1 (PA3) 校准 + 使能 */
  ADS8866_Init();                /* 观测通路: SPI1 + CONVST, 寄存器级, 自包含 */
#ifndef BUTTON_DISABLED
  Button_Init();
#endif
  UART_Init_RX();
  MeasurementState_Init();
  Cal_Init();                 /* 从 Flash 读校准系数 */

#if CAL_MODE != CAL_NONE
  /* ---- 标定固件: 专属主流程 (正常固件 CAL_MODE=CAL_NONE 不编译) ---- */
  OLED_DrawScreen("+0.000", "nA", (CAL_MODE == CAL_ZERO) ? "CAL ZERO" : "CAL BANG");
  UART_SendString((CAL_MODE == CAL_ZERO)
                  ? "CAL ZERO START (10s cycles)\r\n"
                  : "CAL BANG START (1s windows)\r\n");
  CalMode_Start();
  while (1)
  {
    CalMode_Task();
  }
#else
  {
    char buf[80];
    sprintf(buf, "NANO-AMMETER READY (%s)\r\n", clock_source_name);
    UART_SendString(buf);
  }
  OLED_DrawScreen("+0.000", "nA", "MODE:IDLE");
#endif
  /* USER CODE END 2 */

  /* Infinite loop */
  /* USER CODE BEGIN WHILE */
  while (1)
  {
    /* USER CODE END WHILE */

    /* USER CODE BEGIN 3 */
#ifndef BUTTON_DISABLED
    /* 按键任务: 消抖 + 状态机 (非阻塞) */
    Button_Task();
#endif

    /* 测量期间忽略一切指令 (单次语义: 测完自动回 IDLE 后才接受新指令) */
    if (MeasurementState_GetState() == MEASUREMENT_STATE_IDLE)
    {
      /* 串口指令: S=单次测量   D=查询结果
       *           B=内置 ADC 波形  X=ADS8866 波形  E=观测通路自检
       * 参数化指令 (整行):
       *   C                    查询分段系数 a/b
       *   K<段>,<a_ppm>,<b_fA> 写入分段系数        Z 清除分段系数
       *   Q                    查询物理常数 q/I+/I-
       *   Q<q_aC>,<i+_pA>,<i-_pA>  写入物理常数
       *   T<ms>                强制窗口长度 (毫秒); T0 = 回到自动 (1s/<1nA 换长窗)
       *
       * 注意 T 的一进一出, 别混:
       *   T<ms>  (指令, 发进来)  = 设定窗口长度
       *   T=<ms> (结果行, 发出去) = 本次窗口的**实际**时长
       * 两者不是一回事 —— 后者是事实, 前者是要求。结果行里的才是准的。 */
      /* 物理常数与分段系数分成两组指令: 前者是仪器的实测属性, 后者是拟合出来的
       * 修正; 混在一起会让人以为 Z 会把标定好的 q 一起清掉 */
      /* 整行接收: 参数化指令 (K/C/Z) 需要整行; 单字符指令走同一个缓冲,
       * 长度 1 的行就是简单指令 */
      char line[UART_LINE_MAX];
      char cmd = 0x00;

      if (UART_GetLine(line, sizeof(line)))
      {
        cmd = line[0];
        if (cmd == 'K') { Cal_HandleSetLine(line); cmd = 0x00; }
        else if (cmd == 'C') { Cal_Report(); cmd = 0x00; }
        else if (cmd == 'Z') { Cal_Clear(); cmd = 0x00; }
        else if (cmd == 'Q')
        {
          /* 裸 Q = 查询, 带参数 = 写入 */
          if (line[1] == '\0') { Cal_ReportPhys(); }
          else                 { Cal_HandlePhysLine(line); }
          cmd = 0x00;
        }
        else if (cmd == 'T')
        {
          /* T<ms>: **强制窗口长度** (毫秒); T0 = 回到自动 (1s, <1nA 时换长窗)。
           * 1 拍 = 160us -> ticks = ms*1000/160 = ms*25/4。
           * 用途: 1~20 pA 那一段 10s 窗口信噪比不够, 要 50s (T50000)。
           * 按幅值自动切换做不到 —— 20 pA 与 50 pA 都 <1nA, 区分不开。 */
          uint32_t ms = 0U;
          char wbuf[48];
          const char *p = &line[1];
          while ((*p >= '0') && (*p <= '9'))
          {
            ms = ms * 10U + (uint32_t)(*p - '0');
            p++;
          }
          if (ms == 0U)
          {
            MeasurementState_SetForcedWindowTicks(0U);
            UART_SendString("WIN AUTO\r\n");
          }
          else
          {
            MeasurementState_SetForcedWindowTicks((ms * 25U) / 4U);
            sprintf(wbuf, "WIN %lums (%lu ticks)\r\n",
                    (unsigned long)ms,
                    (unsigned long)MeasurementState_GetForcedWindowTicks());
            UART_SendString(wbuf);
          }
          cmd = 0x00;
        }
        else if (cmd == 'M')
        {
          /* M0/M1/M2: 手动阻塞连采 (量 tau / q 开环标定), 结果用 B / X 回传 */
          Current_ManualLine(line);
          cmd = 0x00;
        }
      }
      switch (cmd)
      {
      case 'S':
        MeasurementState_StartCommand();
        OLED_DrawScreen("+0.000", "nA", "MODE1 RUN");
        UART_SendString("START MODE1\r\n");
        break;
      case 'D':
        UART_SendResultQuery();
        break;
      case 'B':
        UART_DumpWaveform();
        break;
      case 'X':
        UART_DumpExtWaveform();
        break;
      case 'E':
        UART_SendExtDiag();
        break;
      default:
        break;
      }

      /* 短按: 启动单次测量 */
#ifndef BUTTON_DISABLED
      if (Button_StartRequested())
      {
        MeasurementState_StartCommand();
        OLED_DrawScreen("+0.000", "nA", "MODE1 RUN");
        UART_SendString("START MODE1\r\n");
        Button_MeasurementDone();
      }
#endif
    }


    /* 测量任务: 非阻塞推进 (TIM6 中断采样, 主循环查状态) */
    Measurement_Task();
  }
  /* USER CODE END 3 */
}

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
/* USER CODE BEGIN 4 */

/* 测量任务: 主循环每轮调用, 非阻塞推进
 * 一次测量 = 1 s 窗口; 若 |I|<1nA 自动换**长窗**重测一次, 然后出结果。
 * 长窗长度 = CURRENT_WIN_LONG_TICKS (2026-09-17 起 50 s, 原 10 s)。
 * 注: 结果行的 MODE= 仍是 1/2 —— 2 表示"用的是长窗口", **具体长度看 T=**。
 *     两条路现在是**同一个公式**, MODE 只是告诉上位机窗口长度不同
 *     (顺带: 长窗口也会出 RAW 段了, 不像原来那个独立的小电流模式)。 */
static void Measurement_Task(void)
{
  MeasurementProcessResult process_result = MeasurementState_Process();

  if (process_result == MEASUREMENT_LONGW_STARTED)
  {
    OLED_DrawScreen("+0.000", "nA", "LONG WIN 50s");
    UART_SendString("LONGW START (I<1nA, 50s window)\r\n");
  }
  else if (process_result == MEASUREMENT_RESULT_READY)
  {
    float current = MeasurementState_GetResult();
    uint8_t longw = MeasurementState_ResultIsLongW();
    uint8_t timeout = MeasurementState_ResultIsTimeout();
    char v[32];     /* 5 位小数下最长 24 字节 + NUL, 24 会截断 */

    has_result = 1;
    FormatCurrentNA(current, v);
    UART_SendResultLine(current, MeasurementState_GetResultExt(),
                        longw ? 2U : 1U, timeout);
    /* timeout 现在表示"拉回相守卫超时"= 读数不可信 (原来是"长窗口超时")。
     * OLED 上要明确写成"数据无效", 不能让人以为只是窗口不一样。 */
    OLED_DrawScreen(v, "nA", timeout ? "INVALID PRE" : (longw ? "MODE:50s" : "MODE:MEASURE"));
  }
}

/* 底噪测量任务: 50s 积分结束后输出拟合偏置电流 (fA 量级) */
/* USER CODE END 4 */
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


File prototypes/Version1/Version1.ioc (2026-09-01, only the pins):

Mcu.UserName=STM32L431CCTx
PA10.Signal=USART1_RX
PA3.Signal=ADCx_IN8
PA9.Signal=USART1_TX
PB1.GPIO_Label=ADG_IN
PB1.Signal=GPIO_Output
PB13.Signal=SPI2_SCK
PB11.Signal=GPIO_Output
PB12.GPIO_Label=OLED_CSI
PB12.Signal=GPIO_Output
PB14.GPIO_Label=OLED_DC
PB14.Signal=GPIO_Output
PB15.Signal=SPI2_MOSI
PB2.GPIO_Label=ADG_EN
PB2.Signal=GPIO_Output

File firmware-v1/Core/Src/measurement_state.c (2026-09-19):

#include "measurement_state.h"
#include "current.h"
#include "tim.h"
#include <math.h>

/* ============================================================
 * 测量状态机 (单次测量语义):
 *   IDLE -> (S 指令) -> 窗口(1s) -> |I| >= 1nA: 出结果, 回 IDLE
 *                                -> |I| <  1nA: 换长窗重测一次 -> 出结果
 *   一次指令 = 一次完整测量, 测完停住 (TIM6 停 + ADG 关断);
 *   无取消/无连续模式 (越简单越可靠), 测量期间忽略一切指令
 *
 * 2026-09-13 重构: **全量程只有一套测量逻辑** (电荷平衡, 见 current.c 的
 * 测量窗口注释)。原来 |I|<1nA 会切到独立的"小电流模式"(参考断开+纯积分),
 * 那是第二套逻辑 —— 符号约定各自实现一遍, 结果就分叉了 (实测抓到一次符号反)。
 * 现在小电流端只是**把窗口从 1 s 拉到 CURRENT_WIN_LONG_TICKS** (现 50 s), 公式一个字都不用改
 * (分母是 m+n, 与窗口长度无关)。
 *
 * 状态也少了一个: 换窗口后仍然停在 MODE1, 只是窗口长了。用一个标志位
 * (long_tried) 保证只换一次, 不会来回切。
 * ============================================================ */

#define DIRECT_MEASURE_THRESHOLD 1e-9f   /* 1nA: 低于则换**长窗**重测
                                          * (长窗长度 = CURRENT_WIN_LONG_TICKS,
                                          *  2026-09-17 起是 50 s; 原 10 s) */

static MeasurementState measurement_state;
static float measurement_result;            /* 内置 ADC 算出的结果 */
static float measurement_result_ext;        /* ADS8866 算出的结果 (表征以它为准) */
static uint32_t measurement_ticks;          /* 本次窗口的实际拍数 (结果行的 T=) */
static uint8_t result_is_longw;             /* 结果是否来自长窗 (结果行 MODE=2) */
static uint8_t result_is_timeout;
static uint8_t long_tried;                  /* 本次测量已经换过长窗 */
static uint32_t precond_to_at_start;        /* 本次测量开始时的 precond_timeout 快照 */
static uint32_t forced_window_ticks;        /* 0 = 自动; 否则每次 S 都用这个窗口长度 */

void MeasurementState_SetForcedWindowTicks(uint32_t ticks)
{
    forced_window_ticks = ticks;
}

uint32_t MeasurementState_GetForcedWindowTicks(void)
{
    return forced_window_ticks;
}

void MeasurementState_Init(void)
{
    measurement_state = MEASUREMENT_STATE_IDLE;
    measurement_result = 0.0f;
    measurement_result_ext = 0.0f;
    measurement_ticks = 0U;
    result_is_longw = 0U;
    result_is_timeout = 0U;
    long_tried = 0U;
}

void MeasurementState_StartCommand(void)
{
    if (measurement_state != MEASUREMENT_STATE_IDLE)
    {
        return;
    }

    /* 每次测量都从短窗口起步 —— 由它决定要不要换长的。
     * 必须在 Current_Start() 之前设: Start 按窗口长度算抽点间隔。
     *
     * 但**强制窗口优先**: 上位机设过就用它, 且 long_tried 直接置 1 让
     * 后面那段自动切换不生效 (否则 <1nA 时会把 50s 窗口换成 10s)。 */
    long_tried = (forced_window_ticks != 0U) ? 1U : 0U;
    precond_to_at_start = precond_timeout;   /* 快照, 用于事后判断本次有没有超时 */
    Current_SetWindowTicks((forced_window_ticks != 0U) ? forced_window_ticks
                                                       : CURRENT_WIN_SHORT_TICKS);

    Current_Start();
    if (HAL_TIM_Base_Start_IT(&htim6) != HAL_OK)
    {
        /* 启表失败必须把参考关掉。Current_Start() 已经 ADG_Enable() 并把拉回相
         * 挂给 ISR 了 (precond_active=1), 而 TIM6 没跑起来 ISR 根本不会执行 ——
         * 参考电流会一直注入、把积分器推到轨上待着。
         * "空闲不注入参考"是最高优先级的安全约定, 不能靠"这条分支不会走到" */
        Current_Stop();
        return;
    }
    measurement_state = MEASUREMENT_STATE_MODE1;
}

/* 单次测量收尾: 停 TIM6 + 关 ADG + 回 IDLE (结果保留在内部供显示/查询) */
static void MeasurementState_Finish(void)
{
    Current_Stop();     /* 停 TIM6 + 关断参考电流 (安全最高优先级) */
    measurement_state = MEASUREMENT_STATE_IDLE;
}

MeasurementProcessResult MeasurementState_Process(void)
{
    float current;
    float current_ext;
    float judge;

    switch (measurement_state)
    {
    case MEASUREMENT_STATE_IDLE:
    default:
        return MEASUREMENT_PROCESSING;

    case MEASUREMENT_STATE_MODE1:
        /* 窗口结果 (中断内算好) */
        if (!Current_WindowFinished())
        {
            return MEASUREMENT_PROCESSING;
        }
        /* 顺序要紧: 先取结果, 再停表, 最后才解除封存 —— 若先解除, 到停表
         * 之间落下一个 TIM6 中断, 会往电压缓冲头部追加窗口外样本 */
        current = Current_GetWindowResult();
        current_ext = Current_GetWindowResultExt();
        HAL_TIM_Base_Stop_IT(&htim6);
        Current_ClearWindowFlag();

        /* 结果行的 T= 用**实际拍数**, 不是 Current_GetSampleCount() ——
         * 后者是抽点后存入缓冲的点数, 长窗下只有 6250, 拿它算 T= 会少报
         * 10 倍 (这正是"注释写拍、实际是点数"那类老坑的新形态) */
        measurement_ticks = Current_GetWindowTicks();

        /* 判据用**外部路 (X=)**, 不用内置路 (I=) —— 2026-09-13 用户裁定:
         * "代码应该和内置 ADC 完全无关"。理由: 拿内置路判的话, 1nA 边界上两路
         * 分歧(内置 1.01 / 外部 0.99)会让**同一个电流落到不同的窗口长度**,
         * 数据前后不一致。而 README 与 main.c 都写明"表征以外部路为准"。
         * 外部路无效(NaN/0)时才退回内置, 免得判据整个失效。 */
        judge = (isfinite(current_ext) && (current_ext != 0.0f)) ? current_ext : current;

        if ((fabsf(judge) < DIRECT_MEASURE_THRESHOLD) && (long_tried == 0U))
        {
            /* <1nA: 换长窗重测一次 (CURRENT_WIN_LONG_TICKS, 现为 50 s)。
             * **同一条测量逻辑**, 只是窗口更长 —— 公式不用改。
             * 1 s 判据窗照旧保留: 它的噪声 0.8 pA, 而判据是 1000 pA,
             * 分辨绰绰有余, 花 1 s 换"该不该换长窗"是划算的。 */
            long_tried = 1U;
            Current_SetWindowTicks(CURRENT_WIN_LONG_TICKS);
            Current_Start();
            if (HAL_TIM_Base_Start_IT(&htim6) != HAL_OK)
            {
                Current_Stop();
                measurement_state = MEASUREMENT_STATE_IDLE;
                return MEASUREMENT_PROCESSING;
            }
            measurement_state = MEASUREMENT_STATE_MODE1;   /* 还是 MODE1, 窗口变长 */
            return MEASUREMENT_LONGW_STARTED;
        }

        /* 出结果 */
        measurement_result = current;
        measurement_result_ext = current_ext;
        /* MODE 由**实际窗口长度**决定, 不用 long_tried —— 后者在强制窗口时被
         * 提前置 1, 会把强制 1s 也报成 MODE=2。真正的窗口长度看结果行的 T=。 */
        result_is_longw = (measurement_ticks > CURRENT_WIN_SHORT_TICKS) ? 1U : 0U;
        /* 拉回相守卫超时 -> 开窗那一拍可能还没到位, 读数不可信, **必须上报**。
         * 判据是"本次测量期间 precond_timeout 有没有涨" —— 不能用它的绝对值,
         * 那是个跨测量只增的累计计数, 看过一次之后就永远非 0。
         * 上报到结果行的 TIMEOUT 后缀 (采集脚本已能解析), 并让 OLED 显示出来。 */
        result_is_timeout = (precond_timeout != precond_to_at_start) ? 1U : 0U;

        /* ---- 首拍在轨 -> 这一窗同样不可信, 一并报成 TIMEOUT ----
         * 2026-09-13 实测: 外部路的 0xFFFF 坏读**聚在窗口开头** ——
         * 平均坏读率 0.085% (32/37500), 而首拍坏读率高达 1/6 = 17%,
         * 相差 200 倍。所以专门查首拍, 不靠平均率去碰运气。
         * (拉回相守卫超时与首拍在轨是两个不同原因, 但含义一样: 读数不可信,
         *  所以复用同一个 TIMEOUT 标记; 结果行与 OLED 都已能显示。) */
        if ((Current_GetFirstCode() >= 0xFF00U) || (Current_GetFirstCode() <= 0x00FFU))
        {
            result_is_timeout = 1U;
        }
        MeasurementState_Finish();
        return MEASUREMENT_RESULT_READY;
    }
}

MeasurementState MeasurementState_GetState(void)
{
    return measurement_state;
}

float MeasurementState_GetResult(void)
{
    return measurement_result;
}

uint32_t MeasurementState_GetTicks(void)
{
    return measurement_ticks;
}

float MeasurementState_GetResultExt(void)
{
    return measurement_result_ext;
}

uint8_t MeasurementState_ResultIsLongW(void)
{
    return result_is_longw;
}

uint8_t MeasurementState_ResultIsTimeout(void)
{
    return result_is_timeout;
}

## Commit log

2026-09-01 纳安表固件: 电荷平衡微弱电流测量 (传递函数反相修正版)
    - 模式一: 滞回电荷平衡 (连续 1s 窗口, ±4.3V 阈值保护)
    - 模式二: 双斜率硬积分 (10s 多循环平均, 电荷注入补偿)
    - 底噪标定: 纯积分 + 最小二乘拟合
    - 电平移位反相映射 V_ad = 1.55 - 0.33*V_o (论文确认)
    - PA3 12-bit 采集路径 + 串口 S/X 指令 + 按键控制
    - SawtoothTest: 独立锯齿波验证工程
    [SH1106.c, Version1.ioc, current.c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]
2026-09-02 合并版固件 OLED_SH1106: 测量状态机+OLED显示+串口协议(S/X/N/D/B) 硬件验证通过
    - 以 OLED_SH1106 为基底合并 Version1 测量核心
    - ADC 时钟改 SYSCLK 80MHz (HAL PLLSAI1 路径对 L431 有缺陷)
    - 寄存器级 ADC 轮询, 防 TIM6 中断内 SysTick 饿死死锁
    - 按键功能全部禁用 (PB4 硬件故障), 控制走串口
    - 串口协议: S/X/N/D/B + 每秒自动上报 + B 波形校验和
    - 新增网页控制台 纳安表控制台.html (Web Serial)
    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
2026-09-02 测量流程改为单次语义: 一次指令=一次完整测量, 测完自动回IDLE
    - 去掉 X 取消指令与连续模式 (越简单越可靠)
    - 测量/底噪期间忽略一切指令
    - B 指令可回传完整窗口数据 (last_window_count)
    - HTML 控制台同步: 去掉停止按钮, S=单次测量
    - SWD 验证: S->1s窗口->结果40.7nA(前端坏时补偿值)->自动回IDLE, 无循环
2026-09-03 新增分模块标定宏 (CAL_ZERO/CAL_BANG) + 共享格式化工具
    - cal_mode.h: CAL_NONE(正常)/CAL_ZERO(零位检查)/CAL_BANG(无输入锯齿波两点标定)
    - 零位检查: 在线最小二乘, 10s 循环上报均值/标准差/漂移/偏置电流
    - bang-bang 标定: 波峰波谷码=切换阈值点, 配万用表 min/max 得传递函数两点标定
    - UART_FormatScaled 上移为共享工具; C_INT/I_POS/I_NEG 上移到 current.h
    - 三种配置均 0 错误 0 警告
    - 说明: 固定电流斜坡不可用(1.67V/ms 3ms 撞轨), 故采用锯齿波阈值停靠点标定
2026-09-04 新增分模块标定宏 (CAL_ZERO/CAL_BANG) + 共享格式化工具
    - cal_mode.h/c: 编译期标定模式宏
    CAL_ZERO: ADG 全断 10s 循环, 上报均值/标准差/漂移斜率/偏置电流 (在线最小二乘, 零缓冲)
    CAL_BANG: 无输入 bang-bang, 每秒上报 m/n/摆幅/波峰波谷码 (传递函数两点标定)
    - C_INT/I_POS/I_NEG 上移 current.h 供标定模块共用
    - current.c 增加 last_m/last_n 与 min/max 码接口
    - UART_FormatScaled 共享定点格式化 (main/cal_mode 共用)
    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
2026-09-11 实机验证版固件 physics_experiment (原 SawtoothTest) + ADC 时钟路径修复
    原工程的 adc.c 用的是 RCC_ADCCLKSOURCE_PLLSAI1, 而这条路径在 L431 上是坏的:
    本工程 HAL 版本对 L431 (PLLSAI1 无 M 分频器) 写出非法配置且不使能 PLL,
    导致 ADC 完全没有时钟 -> 转换永不完成 -> 中断内 HAL 轮询死锁, 采样恒为 0。
    这就是历次锯齿波测试"波形一直是平的"的真正原因。仓库里此前那份快照正是这个坏版本。
    修复与新增:
    - adc.c: ADC 时钟改用 RCC_ADCCLKSOURCE_SYSCLK (80MHz, 在 L431 fADC 上限内),
    并补上单端校准 (校准后 HAL 会关掉 ADEN, 由 ReadRaw 负责重新使能)
    - current.c: ReadR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
    [current.c, current.h, main.c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]
2026-09-11 纳入 nano_ammeter 固件基线
    当前工作树状态导入版本控制 (此前未跟踪)。含本轮测量逻辑修复:
    - 模式二符号反转: 上积相覆盖的是与 I_POS 反号的一支, 结果此前恒印正号
    - 模式一差一: 端点样本间只有 N-1 个间隔, 且第 0 拍计数落在窗口外
    (旧式恒为 I*0.99984 + 8.0pA)
    - 模式二超时不再被当成"电流为零": 新增 ResultIsTimeout(), UART 追加
    TIMEOUT 后缀, OLED 显示 MODE2 TIMEOUT
    - 模式一切换阈值改为判绝对值: 大负电流不再被误送进模式二
    - ADC 转换超时返回上次有效码, 不再伪造 0 这个合法下轨码
    - 底噪压轨判据改为"任一点在轨": 半截平躺的序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
    [cal_mode.c, current.c, current.h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]
2026-09-11 重组目录: 只留 nano_ammeter 一份固件, 历史版本归入 中间测试/
    顶层原来有 4 份平行固件副本, 容易改错目录:
    nano_ammeter/ (活) OLED_SH1106/ (死枝, nano_ammeter 前身)
    Version1/ (旧) physics_experiment/ (旧)
    现在:
    顶层 nano_ammeter/ + 纳安表控制台.html + tools/ + README.md
    中间测试/ OLED_SH1106/ Version1/ Version1.zip physics_experiment/
    用 git mv 移动, 327 个文件全部识别为重命名, 历史完整保留。
    README 结构表同步更新 (原表把 OLED_SH1106 写成"当前正式版", 已过时)。
    构建复验: 0 errors, 0 warnings; RAM 75.94%, FLASH 15.36% (无变化)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
    [SH1106.c, Version1.ioc, cal_mode.c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]
2026-09-12 纳入上位机: 采集脚本 + 控制台当前版 + 自测脚本
    此前这些都在仓库外, 没有任何版本控制:
    - tools/nanoammeter_capture.py (STM32Toolchain/ 根目录)
    - 纳安表控制台.html 当前版 (桌面 07_上位机软件/)
    - 纳安表控制台_自测.js (同上)
    两处修正:
    1. 仓库里的 纳安表控制台.html 是 2026-09-04 11:25 的旧快照,
    桌面上的是同日 17:35 的更新版 (22316 vs 18192 字节, 差 223 行)。
    用桌面版覆盖, 避免"改错地方"。
    2. 采集脚本移入 tools/, 并把本轮改动一并纳入:
    - 捕获结果行 I= 并据此命名 raw_<MM_DD>_<value>nA.npz
    (原先返回值被丢弃, 且固定文件名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
    [nanoammeter_capture.py]
2026-09-12 控制台阶段1: 支持 X / W / E 指令 (WAVEX / NOISE 包头)
    B/X/W 三个二进制块共用一种格式 (固件 UART_DumpBuffer), 只有包头字不同。
    原解析器只认 WAVE, 现按 tag 分流到三个独立槽位, 互不覆盖。
    同时修掉三个问题:
    1. **底噪进度行被当成包头 (会毁数据的真 bug)**
    固件底噪期间每 10s 发一行 "NOISE 10/50s"。原宽松匹配
    /^(WAVE|WAVEX|NOISE) (\d+)/ 会把它读成"N=10 的块", 然后吞掉
    后面 22 字节当二进制 —— 整条数据流从此错位。
    回传头恰为 "<tag> <count>\r\n" 无多余内容, 故用 $ 整行精确匹配。
    由新增测试 T21 抓出。
    2. 坏校验和的块以前仍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
2026-09-12 控制台阶段2-4: 数据存档 + 图表/PNG + 统计量 (真实数据交叉验证)
    三块功能一次并入, 全部无硬件依赖。
    **阶段 3 图表** (纳安表控制台.html)
    - 双路叠加: 外部 ADS8866 在下层, 内置 ADC 在上层, 共用坐标轴
    - 坐标轴: 整齐刻度 (1/2/5×10^n)、网格、轴标签、图例
    - 阈值虚线并标注码值与对应电压
    - 范围计算强制包含两条阈值线, 否则图上看不到
    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
2026-09-12 去掉 JS 里的统计量: 分析交给 MATLAB / Origin
    用户指出这是重复造轮子 —— 相关性、最小二乘、统计量这些标准算法
    MATLAB 一行 corr/polyfit 就够, 没必要在 JS 里重写一遍还多一份出错面。
    删除:
    - HTML 里内联的整个统计量模块 (122 行)
    - 我自己写的 arrStats / logStats 及调用 (59 行)
    - console_src/stats.js + stats_test.js + ref_data.json
    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
2026-09-12 删除底噪测量 (按钮 + 协议 + 导出) 并修正文档
    ## 为什么删
    底噪测量的物理前提不成立:
    - 分辨率下限约 5 fA (内置 ADC 1 LSB = 16 码 -> V_int 2.44mV ->
    100pF 上 50s 折合 4.9 fA), 而 fA 级偏置要积 10^4~10^6 秒
    - 更要命: Noise_Start() 不复位积分器 (只 ADG_Disable + 开 TIM6), 从上次
    测量留下的轨上开始 —— 09-11 数据 50 点全 65520 就是这个原因,
    跑 50 秒还是 1000 秒都一样
    - 与校准固件的 CAL_ZERO 重复 (那边按每 tick 拟合, 且职责清楚)
    用户决定: 验证阶段做几次 1000 秒即可, 正式测试不做 -> 不该挂在日常界面。
    固件侧删除待下次烧录时一并做。
    ##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
2026-09-12 文档分家: README 面向使用, docs/调试与排障.md 面向排障
    用户要求: 项目知识进仓库(随 git 上云), 本地记忆只留已确认与待复测。
    ## 新增 docs/调试与排障.md
    汇总原先散在 README 与本地记忆里的排障内容, 按验证状态分节:
    一、调试手段 —— 烧录命令、nm+mdw 读内存、halt 读 PC 判位置、
    克隆 ST-Link 的 VTref 假警报怎么判(别被它误导)
    二、已验证的工程结论(代码里可查, 非诊断) —— ADC 时钟必须 SYSCLK、
    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
2026-09-12 标注 docs/ 是特定硬件版本的调试记录, 不必要参考
    用户说明: 本项目遇到过的大部分问题根因是**硬件设计错误, 不是软件问题**;
    用户开源方案时会发布修正后的硬件版本。因此这份调试记录属于
    "某一版特定(有缺陷)硬件"的记录, 其中的硬件结论对修正版没有参考价值。
    - docs/调试与排障.md 顶部加醒目警示块 + 逐节"是否可参考"对照表
    · 可参考: 二(固件坑)、六(调试教训)、一(通用 SWD 手段)
    · 仅本版有效: 三(硬件链路)、四(待复核)、五(已排除的怀疑方向)
    - 三、五两节标题各自再加一行就地提醒
    - README 的排障导引处同步加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
2026-09-12 新建 physics_exp_test: nano_ammeter 的整份拷贝 (基线, 尚无功能改动)
    用户决定: 把四项实验表征功能放进独立程序, 竞赛交付固件保持干净。
    四项缺口 (= 两个工程的全部差别):
    ① 分段校准系数 I_cal = a·I_raw + b
    ② 上位机逐点采集 (输入标准值 -> 采 3 次 -> 配对记录 -> 导出)
    ③ 系数下发 (拟合结果写进 MCU)
    ④ 小电流模式 (纯积分 + 斜率, 覆盖 1 pA~1 nA)
    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
2026-09-12 physics_exp_test: 删除底噪测量 (固件侧)
    上位机侧的底噪按钮/协议/导出早已删除, 这次把固件侧一并清掉 ——
    它挂在 Current_Process 里但已无任何触发路径 (N/W 指令已从 uart.c 移除)。
    删除范围:
    - current.c: Noise_Start / Noise_Fit / Noise_Tick / 九个 Noise_* 访问器 /
    状态变量 / Current_GetNoiseVoltage (本来就没有调用者)
    - main.c: Noise_Task / UART_DumpNoiseSeries / noise_mode_active /
    主循环的底噪分支与按键长按分支 / N 与 W 指令
    - current.h: 对应的声明
    顺带把主循环的指令注释更新为当前实际支持的集合。
    **为什么删** (之前已论证): 分辨率下限约 5 fA 而 fA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
    [current.c, current.h, main.c]
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2026-09-12 时钟切到 HSE 晶振 (PLLM=2 绕开一个实测坑)
    用户示波器实测晶振 7.999989MHz, 确认是好的 —— 旧记录"不起振"彻底推翻。
    ## 找到并绕开的坑: PLLM 不能取 1
    逐个试出来的 (板子已接, 全部实测):
    MSI 正常 (原来的配置)
    HSE 直连 (不过 PLL) 时钟切成功但串口读不出
    HSE + PLL, PLLM=1, N=20 **INVSTATE HardFault**
    HSE + PLL, PLLM=2, N=40 **完全正常** <- 采用这个
    PLLM=1 时 VCO 输入 = 8MHz, 在 STM32L4x1/x6 规定的 4~16MHz 内, **是合规配置**;
    查 ST 文档与 erratum 都没找到禁止条款 (只找到 CubeMX 一个"漏写 PLLM、默认
    成 8"的旧 bug)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
    [main.c]
2026-09-12 修 CAL_BANG 从来不工作: TIM6 中断路由错了 (原有 bug, 非本轮引入)
    ## 症状
    切到 CAL_MODE = CAL_BANG 烧录后, 串口一行都不出。
    ## 根因
    current.c 的 TIM6 回调:
    #if CAL_MODE == CAL_NONE
    Current_Process();
    #else
    CalMode_Tick(); /* 标定固件: 节拍路由到标定逻辑 */
    #endif
    而 CalMode_Tick() 内部只有 CAL_ZERO 的代码, CAL_BANG 分支是空的 ——
    注释还写着"CAL_BANG: 采样由 Current_Process 完成", 但那条路根本没被走到。
    于是电压缓冲永远填不满、finish_flag 永远不置位、CalBang_Report 永远不执行。
    **这是原有 bug**: nano_ammeter 与更早的 中间测试/OLED_SH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
    [current.c]
2026-09-12 正式固件换 HSE 晶振 + 同步 CAL_BANG 修复 + 记录分辨力与共模偏移实测
    ## nano_ammeter (正式固件) 换晶振计时
    与 physics_exp_test 用同一配置: HSE 8MHz / PLLM=2 / PLLN=40 / PLLR=2 -> 80MHz,
    带 MSI 兜底 (HSE 起不来就退回, 不 Error_Handler 卡死)。
    READY 行同样报出实际时钟源。**PLLM 不能取 1** —— 实测会 INVSTATE HardFault,
    详见之前的提交与 docs/调试与排障.md。
    ## 同步 ISR 路由修复
    nano_ammeter 的 current.c 里有和 physics_exp_test 一样的路由 bug:
    CAL_BANG 走 CalMode_Tick() (里面只有 CAL_ZERO 的代码), Current_Process 从未被
    调用, 于是 CAL_BANG 固件一行都不出。按防漂移约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
    [cal_mode.c, current.c, main.c]
2026-09-12 采集脚本支持 physics_exp_test: --no-noise + 修结果行解析
    两个问题, 都对着实验固件:
    1. 脚本第 7/8 步发 N/W (底噪), 而 physics_exp_test 已删除这两个指令。
    不加开关会在第 7 步干等 90 秒后抛 TimeoutError, 而 np.savez 在那之后
    —— 一个文件都写不出来。加 --no-noise 跳过这两步, plot_only 跟着支持
    两行布局。
    2. RESULT_RE 写死了 `nA MODE=`, 而实验固件的结果行是
    `I=<内置> X=<外部> MODE=n T=<ms> [CAL=..]`, 中间隔着 X= 字段。
    结果是 capture_name 把文件名静默退化成 raw_MM_DD_NO_RESULT.npz、
    result_na 变 NaN —— 不报错, 只是数据悄悄没了。改成可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
    [nanoammeter_capture.py, test_capture.py]
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2026-09-12 修两个"安静报错"的 bug: UART_FormatScaled 缩放 + 模式一 T=0ms
    都不是崩溃型错误 —— 程序照跑、不告警, 只是报出来的数字错。这类最难发现。
    1) UART_FormatScaled(value, decimals, buf) 只负责插小数点, value 必须由
    调用方自己乘好 10^decimals。全工程 11 个调用点里有 4 处漏乘:
    位置 原乘 应乘 后果
    cal_mode.c DRIFT (两个工程各一处) 1e6 1e8 小 100 倍
    cal_mode.c IB (两个工程) 1e15 1e16 小 10 倍
    cal_mode.c ZERO/NOISE (实验固件) 1.526 152.6 小 100 倍
    nano_ammeter/main.c IBIAS= 1e1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
    [cal_mode.c, main.c, measurement_state.c]
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2026-09-12 回滚 UART_FormatScaled 的缩放改动
    用户明确: 先不要做任何缩放之类。
    那两个 bug 报告 (DRIFT 小 100 倍 / IB 小 10 倍 / ZERO 小 100 倍) 的算术
    是按 UART_FormatScaled 的契约推的 (调用方负责乘好 10^decimals), 但用户的
    判断是: 这类数字不该靠在格式化层凑量级去"修", 而噪声与偏置电流应当来自
    实验测量, 不是靠标称常数和拟合推出来。方向听用户的, 先退回原状。
    同时撤掉 docs 里那节 (原二·补五), 二·补六 顺延为 二·补五。
    保留: 模式一 T=0ms 的修复 (与缩放无关, 是实打实的变量未赋值)。
    保留: 结果行的 RAW 段。
    两个工程构建通过, 零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
    [cal_mode.c, main.c]
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2026-09-12 修上一提交改出的不一致: 开窗极性必须固定 NEG
    上一提交把复位目标改成 0V 时, 顺带让 sel_state 跟着拉回方向走 (从上面拉
    就用 NEG、从下面拉就用 POS)。这破坏了式(6) 的一个不变量:
    n_span = n_count - 1U /* 第 0 拍的计数对应窗口外的 [-1,0] 段,
    所以多出来的那一拍必定是 NEG */
    窗口若以 POS 开, 多出来的那一拍就是 POS, 修正该减 m_count —— 静默算错。
    改回"开窗恒用 NEG"。起点在 0V, 所以这个首相位是正常长度 (到 code_lower
    约 109 拍), 不会像停在阈值上那样退化成 1 拍 —— 拉回 0V 的好处仍然全在。
    切换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
    [current.c]
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2026-09-12 修启表失败留下 ADG 常开 + 补齐 Hi-Z 的文档与上板验证清单
    ## 代码修复 (A2)
    MeasurementState_StartCommand 在 HAL_TIM_Base_Start_IT 失败时直接 return,
    而 Current_Start() 已经 ADG_Enable() 并把拉回相挂给了 ISR (precond_active=1)。
    TIM6 没跑起来 ISR 根本不会执行 -> 参考电流一直注入、把积分器推到轨上待着。
    "空闲不注入参考"是最高优先级的安全约定, 不能靠"这条分支不会走到"。
    改成失败即 Current_Stop(); 并在 Current_Stop() 里一并清 precond_active
    (否则它悬在 1, 下次 Current_Process 会先跑拉回相而不开窗)。
    ## 文档
    * 排障文档新增 二·补六「EN=0 不是 0A, 是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
    [current.c, measurement_state.c]
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2026-09-13 新增 fit_constants.m: 式(6) 三个物理常数的最小二乘拟合 + 自测
    ## 做什么
    把式(6) 的三个常数一起拟合出来:
    I = M·(Vo1 - Vo2)/((m+n)T) - (m·I+ + n·I-)/(m+n)
    M 含电平移位增益的等效电容 (期望 |M| ≈ C/0.33 = 3.03e-10)
    I+ / I- 两个参考电流
    输入一张表 (I_true, c1, c2, m, n), 输出三个参数 + 各自标准误 + 诊断。
    ## 两处数值处理 (用户要求"高精度运算")
    输入是测量值, 本身只有几位有效数字 —— vpa 不会凭空提高准确度。真正要小心的
    是两处**数值**问题, 脚本都避开了:
    ① 码差在**整数域**相减 (c2-c1) 再折算电压。写成 Vref*c2/65536 -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
2026-09-13 新增 docs/校准方案推导.md (报告用) + 修正杠杆分析里一个被数据放大的错误
    ## 新文档: docs/校准方案推导.md
    按"小论文"写成, 可直接作为报告「校准」一节的素材:
    1. 问题的提出 —— 式(6) 里有 7 个标称值, 没有一个测过
    2. 化简 —— 电平移位零点在端点差里**约掉**(不进公式, 不用标);
    C 与电平移位增益**分不开也不用分**(只测乘积 q);
    7 个标称值塌缩成 3 个待测量
    3. 第一个岔路 —— q 为什么不能用"参考断开"测 (EN=0 是 Hi-Z, 12.5% 误差)
    4. 可识别性 —— a2 + a3 ≡ 1 带来的共线, 重参数化后条件数 20
    5. **核心: 三个常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
2026-09-13 修正: 端点差的杠杆是"不受控"的, 不该拿它当依据
    用户指出"任意齿位有波动" —— 对, 而且这是本文同一个量**第二次靠猜**。
    ## 错在哪
    我先是猜端点码差 = ±2000 码, 后来改成 = ±28000 码(假设"终点相位任意")。
    **两次都没有依据, 而它们给出的结论完全相反** (杠杆比 960:1 vs 71:1;
    q 定到 0.45% vs 0.032%)。
    **"终点相位任意"这个假设站不住:**
    窗口长度固定 6250 拍, 锯齿周期由被测电流决定
    -> 终点相位 = 6250 mod 周期(I_x)
    -> **同一个电流重复测, 相位每次都一样**
    重复测量只能压低 Δc 的**噪声**, 不能增加它的**跨度**。跨度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
2026-09-13 工具链: 新增拟合/表征工具, 修 3 个会让队友踩坑的 bug
    新增:
    fit_tau.py 从 M0 波形拟合复位相寄生放电的 tau / C_p / 注入电荷
    measure_transient.py 交替切换法测 C_p (把一次性暂态转成等效直流, 重复平均)
    sim_node_decay.py 100MΩ 输入端节点的电压仿真 (判断示波器探头电容的影响)
    fit_linearity.py 未校准输入-输出关系与线性度 (第 4 章 4.3.3 / 图 4-2)
    matlab_utf8.sh MATLAB 输出 GBK->UTF-8 (见下)
    run_app.sh SWD 手动启动 app (复位不进 app 时用)
    修复 (都是"自测全过但真用起来就挂"那类):
    fit_constants.m 整表 lower() 把 I_true 变成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
    [measure_transient.py, nanoammeter_capture.py, uart_flash.py]
2026-09-13 固件: 新增 M 手动连采模式; 清理双斜率残留; 修正 SI_SETTLE_TICKS
    【新功能】串口 M 指令 —— 阻塞连采, 不走 TIM6 网格
    M0 拉零 -> 断开参考(EN=0) -> 连采 6250 点 => 量 tau / C_p
    M1 拉零 -> 固定 +5V -> 连采 => q 的开环标定
    M2 拉零 -> 固定 -5V => 同上, 另一极性
    M3 高阻 <-> +5V 交替 (每 50 点) => 判别实验 / 交替法测 C_p
    采样直接写进 voltage_buf/_ext, B / X 指令零成本回传; 采样周期用 DWT 实测
    并回显在 MAN DONE 的 tick_ns 里 (实测 23.6us, 不是估的 19.2us)。
    【清理】双斜率硬积分正式废弃
    该模式 1pA 时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
    [current.c, current.h, main.c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]
2026-09-13 数据: 归档 2026-09-13 全部实测数据 (36 个标定点 + 派生结果)
    12 个电流点 x 3 次重复 (±2 ~ ±40 nA), 每点带 raw 段的 m/n/INT/EXT 四个原始量。
    含: 36 个 npz (原始波形+结果行+完整串口转录) / fit_data.csv /
    linearity.png (图 4-2) / M3_waveform.png / node_decay_sim.png
    data/README.md 记了逐点误差表、复现命令, 以及**三个记录上的坑**:
    - +2 / -10 / -30 三点的 true_na 事后改过 (-30 那把 0 抄成了 1)
    - 2636B 输出全程开着, 中途一度误判为"源没开"
    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
    [fit_data.csv]
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2026-09-13 修复: 小电流模式的电流符号反了 (码域与电压域差一层反相)
    现象: 2636B 给 +0.500 nA, 装置读 -0.477 nA (3 次一致 ±1%)。
    同一时刻模式一在 +2.000 nA 上读 +1.98 nA (符号正确)。
    根因: 电平移位是 V_adc = 1.55 - 0.33*V_o, 所以
    Δcode = -0.33*ΔV_o*(65536/3.3)
    —— **积分器电压下降时码值反而上升**, 码域与电压域差一层反相。
    原实现的注释写的是电压域的式子 "I = C·(V_start - V_end)/T" (这个
    在电压域是对的), 但把它直接搬到码域时**漏了这一层反相**:
    I = q·(码_start - 码_end)/T <- 原, 符号反
    I = q·(码_end - 码_s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
    [current.c]
2026-09-13 文档同步 + 归档符号 bug 的证据数据
    文档: README / docs/拟合操作指南.md / docs/第4章撰写流程.md 里的 MATLAB 命令
    统一改为 bash tools/matlab_utf8.sh (中文 Windows 上 MATLAB 的 stdout 实际写
    GBK, 而 -X utf8 这个版本不认)。
    data/signbug/: 符号 bug 的原始证据 —— 2636B 给 +0.0998 nA 时装置读
    -0.086/-0.094/-0.102 nA (全负)。与修后的 +0.488 (同一 0.5 nA 设定)
    形成对照, 是这条修复的实测依据, 故留在仓库里而不是丢弃。
2026-09-13 归档剩余的符号 bug 证据; .gitignore 排除 UART 烧录用的 .bin (构建产物)
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2026-09-13 质量控制: 修 10 处 (含一个会让整轮标定静默产空的致命 bug)
    ★ 致命: 结果行正则遇到 CAL= 就丢掉整个 RAW 段
    固件发 "I=.. nA X=.. nA MODE=1 T=1000ms CAL=+40.235 RAW m=.. n=..",
    而正则的 TIMEOUT/RAW 两组都是可选的, 中间插一个 CAL= 会让正则在它前面收尾 —
    **匹配成功但六个 RAW 字段全是 None**。实测复现:
    无 CAL: raw_m=5003 raw_ext1=58900
    有 CAL: raw_m=None raw_ext1=None
    后果: cal_sweep.py 里 `if c1 is None: continue` 逐行跳过 -> 拟合输入只剩表头,
    需求①② 的整轮扫描**静默产出 0 条结果**, 屏幕上还打着 **无RAW** 把人引向错方向。
    而且 CAL= 是**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
    [cal_mode.c, cal_sweep.py, current.c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]
2026-09-13 实测 ADC 时序 + 定位三个真问题 (含一个会静默出错的首拍坏读)
    【背景】用户追问: "你清不清楚使用 ADS8866 和内置 ADC 的**真实**时序差?"
    答: 不清楚 —— 之前全是按配置推算。于是加了 DWT 计时 + 0xFFFF 计数, 由 E 指令回显。
    ═══ 一、实测出的时序模型 (原来全是推算, 而且我算错了 45%) ═══
    ADS8866_ReadRaw = DWT_DelayUs(T_CONV_US) + 6.36us
    T_CONV_US=9 -> 15.36us (实测)
    T_CONV_US=12 -> 18.36us (实测)
    两次独立测量都给出 6.36us 的固定开销 ==> SPI+GPIO 那部分实为 6.36us,
    我原来算成 1.6us (漏了 GPIO 翻转 / 函数调用 / DWT_DelayUs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
    [cal_mode.c, current.c, current.h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]
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2026-09-13 手动模式: 正式记录前空读一次, 顶掉恒坏的首拍 (待上板验证)
    【问题】Current_ManualRun 的第一拍恒为 0 (见上一条提交的定位)。
    根因是它紧跟在阻塞 PullToZero 的最后一次读之后, 几乎背靠背,
    ADS8866 那次转换被扰动 -> 无效码 0x0000。
    【修法】在读循环之前先 ReadBoth 一次并丢弃 (MANUAL_PREROLL=1)。
    为什么不是"分析时丢掉首点": M0 观测的正是**断开瞬间**的衰减,
    首点就是事件本身, 丢不得 —— 只能让固件多读一次把坏的那次顶掉。
    【代价】18us。丢掉静置后最开头那 18us —— 对 M0 的 tau~490us 是 3.7%,
    比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
    [current.c, current.h, main.c]
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2026-09-14 广泛测试的残差直方图改成用户指定的口径: 修正前 / 修正后
    【用户指定】每大项测试(广泛测量段)只要**两张**直方图:
    ① 直接输出值 vs 回读平均值 = (读数 - 回读)/回读 × 100%
    ② 修正值 vs 回读值 = ((读数-b)/a - 回读)/回读 × 100%
    而不是我原来做的"准确度 / 非线性"。两张放一起才是完整证据链:
    一眼看出修正把**偏置**从多少压到了多少。
    【用昨天的 36 个真实数据算出来 (写进 reg.txt)】
    ① 修正前: σ=0.0849% 均值=+1.1065% 均值/σ=13.03 ← 峰远离 0
    ② 修正后: σ=0.0791% 均值=+0.0534% 均值/σ= 0.68 ← 峰落回 0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
    [sweep_broad.py]
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2026-09-14 入库四张此前游离在仓库根目录的图, 并补全 data/README 的生成方式一列
    这四张图一直没有入库, 散在仓库根目录。移到 data/ (其他图都在这儿),
    并在 data/README.md 的"派生结果"表里逐张写明**是什么、怎么生成的**。
    | 图 | 来源 |
    |---|---|
    | residual_fit.png | tools/fit_constants.m 的输出 (三常数拟合 2x3 图, RMSE 1.5 pA, N=36) |
    | node_decay_sim.png | tools/sim_node_decay.py (README 里原本漏了) |
    | badread_M0.png | M0 参考断开整窗: 6250 点里只有 i=0 一个坏读 |
    | badread_first_sample.png | 同上, 并排 M0 与 M3 (400 点 31 个坏读) |
    | demo_hist.png | 修正前/后两张残差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
2026-09-15 limitv=5V 的理由改对: 不是"超轨就坏", 是"钳位二极管一导通就打开 102mA 的路"
    上一条我写的理由是"20V 比 ±5V 电源轨高 4 倍, 会让保护二极管全导通"。
    用户提醒该上网查, 一查发现理由**说反了**, 但结论反而更硬。
    两条手册事实:
    ADA4530-1: 输入绝对最大值 (V-)-0.3V ~ (V+)+0.3V。超过后钳位二极管导通,
    此时**必须把电流限到 <=10 mA**, 否则永久损坏。
    2600B: "The only exception to the limit not being exceeded is the VLIMIT when
    operating as an ISOURCE. To avoid excessive currents, the VLIMIT will
    source or sink up to 102 mA for ISOURCE ranges on or below 100 mA."
    关键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
    [cal_sweep.py]
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2026-09-15 补一条不用实测的推理: 线性假设被"输入级没烧"证伪, 所需电压 < 6.3V 是硬上界
    "2nA 时 0.5V" 若是线性的 (输入阻抗 250MΩ), 则 45nA 需要 11V;
    而 11V 远超 ADA4530-1 绝对最大值 6.3V -> 钳位二极管导通 -> 打开 102mA 通路
    -> 输入级早该烧掉。但 36 点标定在 ±40nA 上反复跑过且输入级完好。
    => 线性假设不成立, 那 0.5V 是固定偏置或测量假象, 不是负载压降。
    => 所需电压有**硬上界 6.3V**, 且这条上界来自一次已发生且成功的实验, 不依赖新测量。
    于是 5V 这个值的安全性不再悬着: 只要所需电压 < 5V 就完全没问题, 而它必然 < 6.3V。
    仍待实测的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
2026-09-15 修一个蔓延全工具链的静默失效: TSP 里的 `smu.` 应为 `smua.`
    2636B 单独自检跑出来一堆荒唐数字: 设定 45 nA -> 回读 -60.8 pA (偏差 -100%),
    设定 0.01 pA -> 回读 -57.3 pA (偏差 -673%)。回读卡在 -60 pA 附近完全不跟随
    设定值, 输出电压也几乎不动。
    ## 根因: pyvisa 不报 TSP 运行时错误
    错误队列里积了 **35 条**同一条:
    -286 TSP Runtime error at line 1:
    attempt to index global `smu` (a nil value)
    **这台仪器上全局变量 `smu` 是 nil, 只有 `smua` / `smub`**(用户确认用的是 A 通道)。
    所以脚本里每一句 `smu.write('smua.source.output = smu.OUTPUT_ON')` 都在仪器侧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
    [cal_sweep.py, sweep_broad.py, sweep_dc.py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]
2026-09-15 测量精度拉满 (NPLC=10 + autozero), 并修两处标注错误
    ## 短接问题解决了
    用户查明是"两根红色头接一起" —— triax 适配线的红色 = 中心导体, 两根中心
    导体相接就是正确的短路。复测:
    设定 45 nA -> 回读 44.998 nA 偏差 -0.004% V = 82 uV
    ## 精度设置
    实测 NPLC 可调范围 0.01~25 (100 被拒 "Parameter data out of range")。
    读数耗时: NPLC=1 每次 45ms, =10 每次 297ms。
    **没有顶到 25**, 取 10, 理由是算过的而不是拍的:
    本工程是在**装置的 1s 窗口内采多个回读值求平均**, 总积分时间固定 1s。
    NPLC=1 采 22 个 与 NPLC=25 采 2 个, **平均值的噪声几乎一样**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
    [cal_sweep.py]
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2026-09-15 smu_open: 开连接时先读掉残留应答, 否则后续每条 query 都错位一格
    强杀上一个 cal_sweep 之后重跑, smu_open 直接炸:
    型号: 0.00000e+00 <- 应该是 2636B
    RuntimeError: 查错误队列就失败了 (smua.reset()): could not convert
    string to float: '2636B'
    **应答错位了一格**: 读"型号"拿到的是上一条查询的应答, 读"错误队列"拿到了
    "2636B"。根源是仪器输出队列里残留了一条应答(进程被强杀留下的), 而开连接时
    没有任何清空动作。
    症状很有迷惑性 —— 看起来像"型号读出来是 0.00000e+00", 而不是"队列脏了"。
    ## 修法
    新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
    [cal_sweep.py]
2026-09-15 2026-09-15 标定扫描数据 (19 点 x 3 次) —— 自动标定第一次真正跑通
    ## 这是本工程第一次跑通自动标定
    之前 36 点标定数据是手动设源表 + nanoammeter_capture.py(只采集)采的。
    三个自动化脚本从来没驱动过源表 (smu. 那个 bug), 修完后这是第一次端到端跑通。
    采集条件与之前不同, 值得记下:
    - 源表设定: 19 点, +45 -> -45 nA 步长 5
    - NPLC = 10, autozero = ON, limitv = 5V (本次会话新定的设置)
    - 每点装置测 3 次, 每次在测量窗口内采源表回读
    ## 结果: 未校准准确度
    18 个非零点全部落在 +0.99% ~ +1.12%, 即 **+1.04% ± 0.04%**
    **全域恒定的纯增益误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
    [cal_sweep_fit.csv, cal_sweep_raw.csv]
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2026-09-15 新增 tools/cv_linearity.py: 线性度的样本外评估 (固化那个临时脚本) + 低电流段补测
    ## 起因: 用户两处质疑, 都成立
    1. "标定组和用来验证线性模型的要分开" —— 我报的 0.00252 % FS 是**样本内残差**,
    拟合的 3 个参数就是照着同一组 57 行调的, 拿它的残差当线性度是循环论证。
    2. "要求完全等同于代码中的, 完全罗列出来" —— **代码里根本没有拆分**:
    cal_sweep.py 的 DEFAULT_POINTS 19 点全部写进 _fit.csv, fit_constants.m 用
    全部 57 行拟合。那个拆分是我临时写的 heredoc, **没存文件、没提交**, 所以
    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
    [cal_lowI_fit.csv, cal_lowI_raw.csv]
2026-09-15 sweep_broad.py: CSV 补上端点码 m/n/int1/int2/ext1/ext2 (原来没存, 导致套不了式(6))
    ## 缺口
    用户设计的验证方案是**交错点表**: 标定组 `cal_sweep.py` 每 5 nA 一点,
    验证组 `sweep_broad.py` 插在中间 (2~10 nA 每 1 nA; 12.5~40 nA 每 2.5 nA)。
    真正的新验证点 = 6 7 8 9 nA 与 12.5 17.5 22.5 27.5 32.5 37.5 nA
    (其余 10 15 20 25 30 35 40 与标定网格重合, 是重复性检查不是验证)。
    跑完 34 点后发现 **sweep_broad 的 CSV 里只有 dev_nA/true_nA, 没有端点码** ——
    于是只能做 2 参数的线性修正 (读数 = a*真值 + b), **套不了式(6)**, 结论只能
    用 8 pA 的粗模型给出, 而式(6) 在标定数据上是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
    [sweep_broad_run1.csv]
2026-09-15 交错验证点跑完 (补上端点码后, 用式(6) 复算): 真验证点 RMS 1.647 pA
    ## 设计回顾 (用户原设计, 我之前没接上)
    标定组 cal_sweep.py 每 5 nA: 45 40 35 30 25 20 15 10 5 (及负向)
    验证组 sweep_broad.py 插在中间: 2~10 nA 每 1 nA; 12.5~40 nA 每 2.5 nA
    真正的新验证点 = **6 7 8 9 / 12.5 17.5 22.5 27.5 32.5 37.5 nA** (10 个)
    其余 10 15 20 25 30 35 40 与 5nA 网格重合, 是重复性检查、不是验证。
    ## 结果 (式(6) + **只由 19 点标定定出**的常数)
    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
    [sweep_broad.csv]
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2026-09-15 抢救 cal_lowI2 中断前的数据 (只有日志, 端点码已丢)
    用户电脑快没电, 要求跑完当前组就停。但 cal_sweep.py **只在全部 38 点跑完后**
    才写 CSV, 中途被杀 = 全部丢失 (数据只攒在内存的 rows 里, 没有增量落盘)。
    抢救出: 完成 2 个点 (+2 pA / +4 pA), 第 3 个点跑到一半。
    **丢失**: 端点码 m/n/INT1/INT2/EXT1/EXT2 —— 那些只进内存没打印, 所以这批
    数据**套不了式(6)**, 只能看"装置读数 vs 源表回读":
    +2 pA 装置 +0.0000 源表 +0.00182 -100.0%
    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
    [lowI2_partial.csv]
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2026-09-16 一批: 波特率定案 115200 + 162 点密集标定 + 波形反推 + 低电流方案
    ## 固件/上位机波特率 —— 试了两档, **定案保持 115200**
    整窗 12500 字节回传, 每档至少 16 次实测:
    115200 1.085 s **全清** (09-13 起几百次没坏过)
    921600 0.147 s 89% 一次成功, 11% 需重传; 重传后 0 丢失
    2000000 0.073 s 1/16 成功, 13/16 连 4 次重传全失败 -> 不可用
    失败率随波特率**单调上升** -> 是 CH340G 的带宽问题。中途怀疑过地线松,
    接好后 2 Mbps 重测**反而更差** (19%), 排除接地。固件是阻塞式
    HAL_UART_Transmit, MCU 侧不可能丢 —— 丢在 CH340G -> USB -> 主机 这一段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
    [cal_table.csv, mn_endpoint_counts.csv, outlier_residuals.csv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]
2026-09-19 开源整理: 硬件文件 + 控制台修复 + 亚纳安窗口改 50s + 工具索引
    硬件
    - hardware/: 原理图 + 4 层 Gerber + 钻孔（来自 OPEN.zip）
    已核对 Gerber 注释里不含姓名/路径/邮箱等个人信息
    文档
    - README: 补项目介绍 —— 原理(式6)/指标/系统组成/窗口策略/快速开始
    - README: 修掉两处过时表述 —— 串口是 115200 不是 2 Mbps
    (2 Mbps 是板载 CH340G 带宽上限, 当天已改回)
    - tools/README.md: 新增按功能分组的脚本索引
    固件 (physics_exp_test)
    - <1 nA 的长窗由 10 s 改为 50 s (current.h 的 CURRENT_WIN_LONG_TICKS)
    实测依据: 10 s 窗单次重复性 0.1153 pA, 50 s 窗 0.0267 pA
    - FormatC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
    [Drill_NPTH_Through.DRL, Drill_PTH_Through.DRL, Drill_PTH_Through_Via.DRL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]
2026-09-20 论文数据表与常数口径: 正负分表 + 检测下限 + 光电效应对比图
    表 (tools/report_table.py)
    新增 --sign pos|neg|both 与 --exclude-na, 支持论文附录的**正负分表**:
    data/dense_table_pos_na.csv 77 点 (81 - 4)
    data/dense_table_neg_na.csv 81 点
    data/dense_table_na.csv 162 点合表 (保留)
    CSV 带 UTF-8 BOM + LF + 定点十进制 —— Excel 双击即开。
    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
    [dense_table_na.csv, dense_table_neg_na.csv, dense_table_pos_na.csv]
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2026-10-09 数据与插图: 补 I–V 曲线数据, 重出光电效应与残差插图
    - data/: 新增光电探测器 I–V 曲线与暗电流数据 (iv_*.csv / *_dark), 重出
    cal_162.png、rel_accuracy_5_45.png、photo_data_*.png
    - image_paper/: 新增 fig03/fig06b/fig06c, 重出 fig02/fig04/fig07~09;
    IMAGE_SPEC.md 记入三常数用拟合小数 CONST_FIT 的裁定
    [_prev_577_2V.csv, iv_365_check.csv, iv_365nm.csv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]
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2026-10-09 硬件: 上传铝合金外壳 3D 模型 hardware/enclosure.stp
    嘉立创 FA 铝合金壳体, STEP AP214, 658 KB。README 补入说明。
    文件头作者字段是嘉立创导出模板默认占位, 非设计者信息。
    [enclosure.stp]
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
